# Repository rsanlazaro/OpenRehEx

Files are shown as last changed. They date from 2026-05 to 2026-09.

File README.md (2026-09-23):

# OpenRehEx
**Open-Source Lower Limb Rehabilitation Exoskeleton**

OpenRehEx is an open-source lower-limb rehabilitation exoskeleton that integrates
motor **torque, speed, and position feedback** using CubeMars AK70-10 actuators,
biomechanically inspired gait trajectories, and a CAN-based embedded control system.

This repository provides **all design files and source code** required to reproduce,
modify, and extend the system.

---

## Project Overview

**OpenRehEx** is designed to promote:

- Accessibility in rehabilitation robotics
- Reproducible research
- Rapid prototyping and customization

The project includes:

- CAD design of a bilateral lower-limb exoskeleton with 3 actuated joints per leg
  (hip, knee, ankle — 6 DoF in total, sagittal plane)
- MATLAB app for biomechanically scaled gait trajectories
- CAN protocol implementation for CubeMars AK70-10 motors (MIT mode)
- Arduino firmware for real-time control of all six motors with safety supervision
- Integrated motor feedback (position, speed, torque)
- Real-time visualization interface in Python

---

## System Architecture

The complete system is organized into five stages. The full description, control
hierarchy, operating states and loop timing are in
[`docs/system_architecture.pdf`](docs/system_architecture.pdf).

1. **Trajectory Generation** — Gait trajectories are generated in MATLAB from
   gait speed, step length, amplitude scale and smoothness. The exported CSV is
   converted into a flash lookup table for the firmware
   (`Arduino/Motor_Control/gait_trajectory.h`) with `csv_to_header.py`.

2. **Microcontroller (Control)** — An Arduino MEGA 2560 runs a fixed-rate 200 Hz
   loop that tracks the gait trajectory on all six joints (left leg shifted by
   50 % of the stride), enforces the mechanical range of motion, supervises the
   motors, and handles CAN communication.

3. **CAN Bus Interface** — An MCP2515 module (SPI) bridges the Arduino and the
   CAN bus at 1 Mbps. Only two wires (CAN_H and CAN_L) daisy-chain all motors,
   with a 120 Ω termination resistor at each end of the bus.

4. **Actuation** — Six CubeMars AK70-10 motors, powered by an external 24–48 V DC
   supply through a fuse and a hardware emergency stop, controlled in MIT
   (impedance) mode: τ = kp·(p_ref − p) + kd·(v_ref − v) + τ_ff.

5. **Visualization** — The control MEGA sends telemetry over UART to a second
   Arduino MEGA 2560, which validates it and forwards it over USB to a Python
   interface for real-time monitoring of trajectory tracking, torque and
   velocity. This stage is optional; the exoskeleton operates independently of it.

Wiring for the complete system: [`docs/wiring_diagram.pdf`](docs/wiring_diagram.pdf).
Single-motor bench wiring: [`CAN_Protocol/CAN_connection.png`](CAN_Protocol/CAN_connection.png).

---

## Degrees of Freedom

| Joint  | Plane | Actuation | Range of motion (deg) | CAN ID (Right / Left) |
|---|---|---|---|---|
| Hip | Sagittal plane | AK70-10 | −20 (extension) to 40 (flexion) | 0x01 / 0x04 |
| Knee | Sagittal plane | AK70-10 | 0 to 50 (flexion) | 0x02 / 0x05 |
| Ankle  | Sagittal plane | AK70-10 | −20 (plantarflexion) to 20 (dorsiflexion) | 0x03 / 0x06 |

The ranges are the mechanical limits used by the MATLAB generator and enforced as
soft limits by the firmware.

---

## Repository Structure

```
OpenRehEx/
├── CAD/                                  # SolidWorks parts (.SLDPRT) and assemblies (.SLDASM)
│   ├── Hip/                              # Left/right hip covers, waist supports, side supports
│   ├── Knee/                             # Left/right thigh links, knee covers, motor base
│   ├── Ankle/                            # Left/right shank links, foot plates, ankle covers
│   └── Assembly/                         # Full assembly (OpehRehEx_V1.SLDASM), back, waist, AK70-10 model
├── MATLAB/
│   ├── trajectory_generator.m            # App: gait trajectory generator and exporter
│   ├── gait_parameters.m                 # Reference table of gait parameters (slow/normal/fast)
│   └── examples/                         # Slow, normal and fast gait demos + run_all_examples.m
├── Arduino/
│   ├── main.ino                          # Control MEGA firmware (6 motors, console, telemetry)
│   ├── CAN_Driver/
│   │   └── CAN_Driver.h                  # AK70-10 MIT protocol over MCP2515 (header-only)
│   ├── Motor_Control/
│   │   ├── Motor_Control.h               # State machine, gait reference, safety supervisor
│   │   ├── gait_trajectory.h             # Auto-generated gait table (PROGMEM)
│   │   └── csv_to_header.py              # MATLAB CSV → gait_trajectory.h
│   └── Graphs_visualization/
│       ├── ArduinoMEGA_receiveSerial/    # Visualization MEGA firmware (UART → USB relay)
│       ├── GUI_plotting_V4.py            # Real-time plotting interface (PyQt5 + Matplotlib)
│       └── requirements.txt
├── CAN_Protocol/
│   ├── motor_commands.md                 # Frame layouts, scaling, IDs, command sequence
│   ├── CAN_connection.png                # Single-motor bench wiring
│   └── CubeMarstool_V1.32.exe            # Vendor tool (IDs, firmware, MIT limits)
├── docs/
│   ├── system_architecture.pdf
│   ├── wiring_diagram.pdf
│   └── src/build_docs.py                 # Regenerates both PDFs
├── Trajectory_generation.m               # Standalone function version of the generator (legacy)
├── LICENSE
└── README.md
```

---

## Hardware Requirements

| Component | Specification / Model |
|---|---|
| Actuators | CubeMars AK70-10 (24–48 V) × 6 |
| Microcontroller | Arduino MEGA 2560 × 2 (control + visualization) |
| CAN interface module | MCP2515 with 8 MHz crystal |
| CAN transceiver | TJA1050 (integrated in the MCP2515 module) |
| Power supply | DC 24–48 V, sized for the combined current of six motors |
| Safety | Main fuse + hardware emergency stop on motor V+ |
| Bus termination | 120 Ω resistors × 2 (one can be the MCP2515 J1 jumper) |
| Cables | Twisted pair for CAN, 2 × USB (A–B) to the PC |

> The 15 A supply shown in `CAN_connection.png` was used for the single-motor
> bench setup. Size the supply, fuse and wiring for all six motors.

---

## MATLAB Trajectory Generator

`trajectory_generator.m` is a MATLAB app that generates **hip, knee, and ankle
trajectories** for both legs from:

- Gait speed (m/s) and step length (m) — cadence, step time and stride time are derived
- Number of gait cycles and points per trajectory
- Amplitude scale (for progressive, sub-maximal range of motion)
- Smoothness level (1–10)

Keypoints are based on Oberg et al. (1993), Kwon et al. (2015), Lim et al. (2017) and
Judge et al. (1996), clamped to the exoskeleton's mechanical limits and interpolated
with periodic PCHIP. Presets are provided for slow, normal and fast gait.

**Exports** (written to the current folder):

| File | Content |
|---|---|
| `exoskeleton_trajectories.mat` | Trajectories (both legs), parameters, limits, references |
| `exoskeleton_trajectories.csv` | `Time_s, Hip, Knee, Ankle` (right leg) |
| `exoskeleton_trajectories.txt` | Same data with a commented header |
| `exoskeleton_trajectories_arduino.txt`| Float arrays, both legs, ×10 downsampled, ×0.75 scaled |

The firmware uses the **CSV**, converted to a compact integer table stored in flash:

```
python Arduino/Motor_Control/csv_to_header.py --csv exoskeleton_trajectories.csv --units deg --cycles 3
```

`--cycles` must match the number of gait cycles set in the app, and `--units` the
selected output unit. `python csv_to_header.py --baseline` rebuilds the default table
(nominal gait, 1.40 m/s, 0.73 m step).

The same model is available as a function in `Trajectory_generation.m`:

```matlab
[hip, knee, ankle, t] = generate_exoskeleton_trajectories('gait_speed', 1.0, 'step_length', 0.6, 'smoothness', 9);
```

Joint conventions: hip and knee positive = flexion; ankle positive = dorsiflexion.

---

## Firmware

`Arduino/main.ino` runs on the control MEGA and uses the two header-only modules
in `CAN_Driver/` and `Motor_Control/`. Dependency: **`mcp_can`** by coryjfowler
(Arduino Library Manager).

**Operating states:** DISABLED → HOLD → RAMP_IN → WALKING → RAMP_OUT → HOLD, plus
FAULT. Transitions into and out of walking are 3 s cosine ramps.

**Safety supervision:** the controller enters FAULT (damping only, kp = 0) if a motor
does not reply for 50 ms, a joint leaves its range by more than 0.15 rad, or a motor
reports an error code. FAULT is not a substitute for the hardware emergency stop.

**Operator console** (Serial Monitor on the control MEGA, 115200 baud):

| Key | Action |
|---|---|
| `e` | Enable: enter MIT mode, zero encoders, hold posture |
| `s` | Start walking (ramp in) |
| `p` | Pause: ramp back to neutral standing and hold |
| `d` | Disable: exit MIT mode (motors become free) |
| `c` | Clear a fault and hold the current posture |
| `z` | Set encoder zero at the current posture (DISABLED / HOLD only) |
| `+` `-` | Amplitude ± 0.05 (0 – 1, default 0.5) |
| `f` `l` | Stride time − / + 0.25 s (0.8 – 10 s, default 3 s) |
| `?` | Status: joint positions, torques, faults, loop timing |

Joint IDs, directions, soft limits and gains (default kp = 60 N·m/rad,
kd = 1 N·m·s/rad) are set in the `JOINTS[]` table of `main.ino`.

---

## CAN Protocol

Motor commands and feedback use the CubeMars MIT protocol (CAN 2.0A, 1 Mbps, 8-byte
frames): special frames to enter/exit MIT mode and set zero, one command frame
(position, velocity, kp, kd, feed-forward torque) and one reply (motor ID, position,
velocity, torque, and on newer firmware temperature and error code) per motor per
cycle. Full definitions, scaling ranges, worked examples and troubleshooting are in
[`CAN_Protocol/motor_commands.md`](CAN_Protocol/motor_commands.md).

---

## Visualization Interface

`GUI_plotting_V4.py` plots the six motors in real time (right leg / left leg columns)
and can switch between **position vs. reference**, **torque**, and **velocity**
(computed from position and timestamp). It includes a median-based spike filter,
left/right range-of-motion comparison per joint, a restart button, and export of the
session to `session_data` TXT/CSV files.

Telemetry format (one line per sample, integers):

```
motor_id,timestamp_ms,ref_mrad,pos_mrad,torque_mNm
```

---

## Getting Started

1. **Mechanical assembly** — Open `CAD/Assembly/OpehRehEx_V1.SLDASM`, export the parts
   to STL, then print and assemble them.
2. **Motor setup** — With CubeMarsTool, assign each motor a unique CAN ID (0x01–0x06,
   one motor at a time) and read its MIT scaling limits. Select the matching limits
   in `setup()` of `main.ino` (see `motor_commands.md`, section 5).
3. **Wiring** — Follow `docs/wiring_diagram.pdf`.
4. **Trajectory generation** — Generate trajectories in MATLAB and convert the CSV
   with `csv_to_header.py`.
5. **Firmware upload** — Install `mcp_can`, then upload `Arduino/main.ino` to the
   control MEGA and `Arduino/Graphs_visualization/ArduinoMEGA_receiveSerial/` to the
   visualization MEGA.
6. **First run** — Without a user, place the exoskeleton at neutral standing posture,
   press `e`, and verify each joint moves in the correct direction (flip `direction`
   in `JOINTS[]` if needed). Test the emergency stop.
7. **Visualization** — `pip install -r Arduino/Graphs_visualization/requirements.txt`,
   set `COM_PORT` in `GUI_plotting_V4.py` to the visualization MEGA's port, and run it.

> **Safety:** the encoders are zeroed on every enable, so always enable at neutral
> posture. Start with low amplitude and long stride times, and support the user
> (harness or parallel bars) before disabling the motors or pressing the E-stop.

---

## License

This project is released under the MIT License, unless otherwise stated.
See [LICENSE](LICENSE) for details.

---

## Citation

If you use OpenRehEx in your research, please cite:

```bibtex
@article{OpenRehEx2026,
  title   = {OpenRehEx: A Lower Limb Open-Source Rehabilitation Exoskeleton
             with Integrated Motor Torque, Speed, and Position Feedback},
  author  = {Rafael P\'{e}rez-San L\'{a}zaro, Fuentes-Aguilar Rita Q., Isaac Chairez},
  year    = {2026}
}
```

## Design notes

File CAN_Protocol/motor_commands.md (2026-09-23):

# CubeMars AK70-10 — CAN Motor Commands (MIT mode)

This document describes every CAN frame that OpenRehEx exchanges with the six
CubeMars **AK70-10** actuators, and how those frames are produced and decoded by
`Arduino/CAN_Driver/CAN_Driver.h`.

> **Source of truth.** Frame layouts follow the CubeMars *AK Series Actuator
> Manual*, section "MIT power mode communication protocol". Scaling ranges can
> change between firmware versions — always confirm them for **your** motors
> with `CubeMarstool_V1.32.exe` (in this folder) before running the exoskeleton
> with a person in it.

---

## 1. Bus configuration

| Parameter | Value |
|---|---|
| Standard | CAN 2.0A (11-bit standard identifier) |
| Bit rate | 1 Mbps (AK factory default) |
| Payload | 8 bytes (commands), 6 or 8 bytes (replies) |
| Topology | Linear bus, daisy-chained through each motor's CAN IN/OUT port |
| Termination | 120 Ω between CAN_H and CAN_L at **both** physical ends |
| Controller | MCP2515 + TJA1050 module, 8 MHz crystal, SPI to Arduino MEGA 2560 |
| Arduino library  | `mcp_can` by coryjfowler |

### Motor ID map

IDs are assigned with CubeMarsTool (factory default is `0x01` for every motor,
so each motor must be re-addressed **one at a time** before joining the bus).
The map matches `JOINTS[]` in `Arduino/main.ino` and `MOTOR_META` in
`Arduino/Graphs_visualization/GUI_plotting_V4.py`.

| CAN ID | Joint | Side  |
|:---:|---|---|
| `0x01` | Hip | Right |
| `0x02` | Knee | Right |
| `0x03` | Ankle | Right |
| `0x04` | Hip | Left  |
| `0x05` | Knee | Left  |
| `0x06` | Ankle | Left  |

---

## 2. Special commands

Sent to the motor's CAN ID, 8 data bytes. Only the last byte changes.

| Command | Data (hex) | Effect | Driver call |
|---|---|---|---|
| Enter MIT mode | `FF FF FF FF FF FF FF FC` | Enables the motor; it starts answering MIT frames | `enterMit(id)` |
| Exit MIT mode | `FF FF FF FF FF FF FF FD` | Disables the motor (free / back-drivable) | `exitMit(id)` |
| Set zero position  | `FF FF FF FF FF FF FF FE` | Current output-shaft angle becomes 0 rad | `setZero(id)` |

> ⚠ **Set zero** redefines the joint reference. OpenRehEx sends it on every
> `enable` (`zero_on_enable = true`, same behaviour as the original sketch), so
> the exoskeleton **must be in the neutral standing posture** (hip 0°, knee 0°,
> ankle 0°) when the operator types `e`. Set `zero_on_enable = false` in
> `DEFAULT_SETTINGS` once zeroing is done with a fixture instead.

---

## 3. Control command (Arduino → motor)

Every control cycle the firmware sends one 8-byte frame per motor. The motor
closes an impedance loop at the output shaft:

```
tau = kp * (p_des - p) + kd * (v_des - v) + t_ff
```

### Fields

| Field | Bits | Unit | Meaning |
|---|:----:|---|---|
| `p_des` | 16 | rad | Desired output position |
| `v_des` | 12 | rad/s | Desired output velocity |
| `kp` | 12 | N·m/rad | Position (stiffness) gain |
| `kd` | 12 | N·m·s/rad | Velocity (damping) gain |
| `t_ff`  | 12 | N·m | Feed-forward torque |

### Byte layout

| Byte | Bits 7‥4 | Bits 3‥0 |
|:----:|---|---|
| 0 | `p_des[15:8]` | |
| 1 | `p_des[7:0]` | |
| 2 | `v_des[11:4]` | |
| 3 | `v_des[3:0]` | `kp[11:8]` |
| 4 | `kp[7:0]` | |
| 5 | `kd[11:4]` | |
| 6 | `kd[3:0]` | `t_ff[11:8]` |
| 7 | `t_ff[7:0]` | |

---

## 4. Reply (motor → Arduino)

The motor answers **each** control frame (and only then). The reply is sent to
the master ID (default `0x00`); the motor ID is inside the payload, so replies
are routed by **byte 0**, not by the CAN identifier.

| Byte | Content |
|:----:|---|
| 0 | Motor ID |
| 1 | `p[15:8]` |
| 2 | `p[7:0]` |
| 3 | `v[11:4]` |
| 4 | `v[3:0]` (high nibble) · `i[11:8]` (low nibble) |
| 5 | `i[7:0]` |
| 6 | Driver temperature *(firmware ≥ V2 only)* |
| 7 | Error code *(firmware ≥ V2 only)* |

`i` is scaled with the torque range (`T_MIN … T_MAX`), so it decodes directly
to output torque in N·m.

### Error codes (byte 7)

| Code | Meaning |
|:----:|---|
| 0 | No fault |
| 1 | Motor over-temperature |
| 2 | Over-current |
| 3 | Over-voltage |
| 4 | Under-voltage |
| 5 | Encoder fault |
| 6 | Phase-current unbalance  |

With `fault_on_motor_error = true` any non-zero code puts the controller in
`FAULT` (damping only). Replies of 6 bytes (older firmware) carry no status and
never trigger this check. The temperature byte is stored raw (`temp_raw`)
because its offset differs between firmware versions.

---

## 5. Scaling (float ↔ integer)

All values are linearly mapped onto unsigned integers:

```
x_int   = round( (x - x_min) * (2^bits - 1) / (x_max - x_min) )
x_float =  x_int * (x_max - x_min) / (2^bits - 1) + x_min
```

Values outside `[x_min, x_max]` are saturated before packing.

### Ranges

| Symbol | AK70-10 (CubeMars manual) — **used by default** | Original sketch (`AK_LEGACY_SKETCH_LIMITS`) |
|---|:---:|:---:|
| `P_MIN / P_MAX` | −12.5 / 12.5 rad | −12.5 / 12.5 rad |
| `V_MIN / V_MAX` | −50 / 50 rad/s | −30 / 30 rad/s |
| `KP_MIN / KP_MAX` | 0 / 500 N·m/rad | 0 / 500 N·m/rad |
| `KD_MIN / KD_MAX` | 0 / 5 N·m·s/rad | 0 / 5 N·m·s/rad |
| `T_MIN / T_MAX` | −25 / 25 N·m | −18 / 18 N·m |

> ⚠ **Why this matters.** If the firmware uses ±50 rad/s and ±25 N·m but the
> code packs with ±30 and ±18, every velocity and torque value is wrong by a
> constant factor (e.g. torque read as 72 % of its real value), while position
> still looks correct. Some third-party drivers list ±24 N·m for AK70-10
> firmware V1.1. Read the ranges in CubeMarsTool and select the matching
> constant in `setup()` (`canBus.setLimits(...)`).

### Resolution (with the default ranges)

| Quantity | Step |
|---|---|
| Position | 0.00038 rad (0.022°) |
| Velocity | 0.0244 rad/s  |
| Torque | 0.0122 N·m |
| `kp` | 0.122 N·m/rad |
| `kd` | 0.0012 N·m·s/rad |

### Worked examples (default ranges)

| `p_des` | `v_des` | `kp` | `kd` | `t_ff` | Frame (hex) |
|---:|---:|-----:|-----:|---:|---|
| 0 | 0 | 0 | 0 | 0 | `80 00 80 00 00 00 08 00` — passive, used to read state |
| 0.5 | 0 | 60 | 1 | 0 | `85 1E 80 01 EB 33 38 00` |
| 1.234 | −3.2 | 60 | 1 | 2.5 | `8C A2 77 C1 EB 33 38 CC` |

---

## 6. Command sequence used by the firmware

```
enable (console 'e')
  for id in 1..6:  ENTER_MIT(id) ; [SET_ZERO(id)]
  for id in 1..6:  PASSIVE(id) -> wait reply (≤ 5 attempts) -> store position
  state = HOLD (reference = measured posture)

every control period (default 200 Hz)
  for id in 1..6:
      send MIT command(id)            # p_des, v_des (feed-forward), kp, kd, t_ff = 0
      wait reply from id (≤ 1.5 ms)   # one request/one reply keeps the MCP2515
                                      # 2-frame RX buffer from overflowing
  supervise:  no reply > 50 ms | angle outside limits + 8.6° | error code ≠ 0
              -> FAULT: kp = 0, kd = 2, t_ff = 0 on all joints

disable (console 'd')
  for id in 1..6:  EXIT_MIT(id)       # motors become free: support the limb!
```

**Why request/reply per motor?** The MCP2515 has only two receive buffers. If
six commands are sent back-to-back, up to six replies arrive within ~0.7 ms and
four are lost. Waiting for each reply before sending the next command costs
~0.4–0.6 ms per motor, which still fits inside a 5 ms (200 Hz) cycle. The
console command `?` prints the worst-case loop time and the overrun counter; if
overruns increase, set `CONTROL_HZ` to 100.

---

## 7. Telemetry to the PC (not CAN)

The control MEGA sends one line per control cycle on `Serial1` (round-robin over
the six motors). The visualization MEGA validates and forwards it over USB to
`GUI_plotting_V4.py`.

```
motor_id,timestamp_ms,ref_mrad,pos_mrad,torque_mNm\n
e.g.  2,445473,611,598,4130
```

All values are integers in **joint coordinates** (sign convention of
`trajectory_generator.m`: hip/knee + flexion, ankle + dorsiflexion).

---

## 8. Servo mode (not used)

AK actuators also support a *servo mode* that uses **extended 29-bit IDs**
(`control_mode << 8 | motor_id`) and different payloads (duty, current, RPM,
position). OpenRehEx uses MIT mode only because it exposes the impedance gains
needed for assist-as-needed control. Do not mix both modes on the same bus.

---

## 9. Troubleshooting

| Symptom | Likely cause / fix |
|---|---|
| `MCP2515 init failed` | SPI wiring, CS ≠ D53, or crystal is 16 MHz → use `MCP_16MHZ` |
| No replies, `FAULT_ENABLE_FAILED` | Wrong ID, motor not powered, missing termination, CAN_H/CAN_L swapped |
| Only one motor answers | All motors still have ID `0x01` — re-address them one by one |
| Position OK, torque/velocity look scaled  | `MitLimits` do not match the firmware (section 5) |
| Joint moves the wrong way | Flip `direction` for that joint in `JOINTS[]` |
| Random `FAULT_NO_REPLY` while walking | Bus length/stubs too long, missing common ground, loop overruns |
| Motor jumps on enable | Exoskeleton was not at neutral posture when zero was set |

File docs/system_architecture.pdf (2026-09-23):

# OpenRehEx — System Architecture

Open-source 6-DoF lower-limb rehabilitation exoskeleton · end-to-end data flow from trajectory design to actuation and monitoring

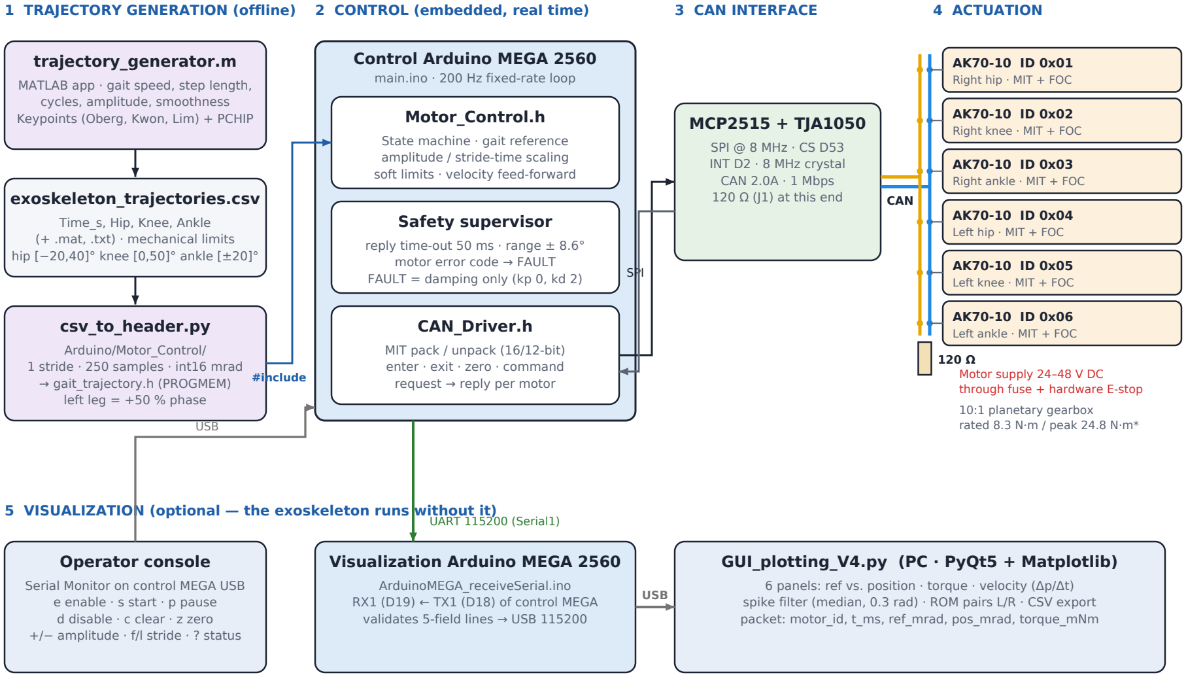
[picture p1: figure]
1 TRAJECTORY GENERATION (offline); trajectory_generator.m; MATLAB app · gait speed, step length, cycles, amplitude, smoothness Keypoints (Oberg, Kwon, Lim) + PCHIP; exoskeleton_trajectories.csv; Time_s, Hip, Knee, Ankle (+ .mat, .txt) · mechanical limits hip [−20,40]° knee [0,50]° ankle [±20]°; csv_to_header.py; Arduino/Motor_Control/ 1 stride · 250 samples · int16 mrad → gait_trajectory.h (PROGMEM) left leg = +50 % phase; 2 CONTROL (embedded, real time); Control Arduino MEGA 2560; main.ino · 200 Hz fixed-rate loop; Motor_Control.h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

OpenRehEx · System architecture · github.com/rsanlazaro/OpenRehEx | Page 1 of 3
5 VISUALIZATION (optional — the exoskeleton runs | without it)

### GUI_plotting_V4.py (PC · PyQt5 + Matplotlib)

6 panels: ref vs. position · torque · velocity (Δp/Δt)
spike filter (median, 0.3 rad) · ROM pairs L/R · CSV export packet: motor_id, t_ms, ref_mrad, pos_mrad, torque_mNm

* Vendor-listed AK70-10 figures; confirm against the datasheet of your units. Colors: yellow CAN_H · blue CAN_L · green UART · gray USB.

# Control Architecture & Firmware

### Control hierarchy, operating states and the real-time cycle of the control MEGA

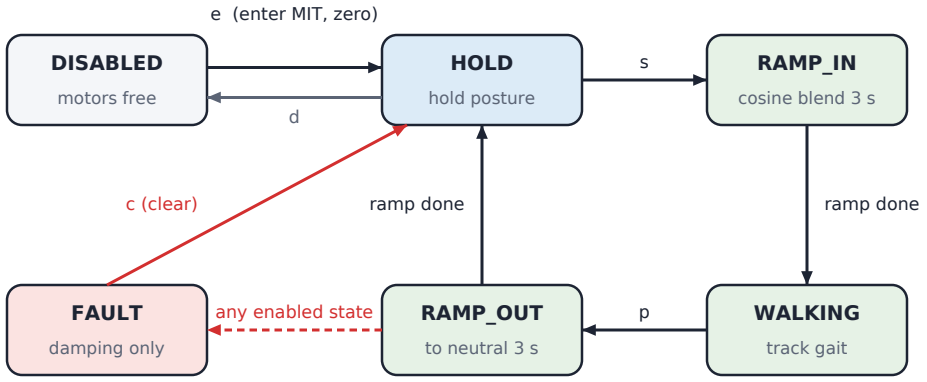
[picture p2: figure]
DISABLED; motors free; HOLD; hold posture; RAMP_IN; cosine blend 3 s; WALKING; track gait; RAMP_OUT; to neutral 3 s; FAULT; damping only; e (enter MIT, zero); ramp done; c (clear); any enabled state

OpenRehEx · System architecture · github.com/rsanlazaro/OpenRehEx | Page 2 of 3

## Control hierarchy

HIGH LEVEL — adaptation (roadmap)

Q-learning agents: Recovery Estimator + Therapy Tuner
Adjust amplitude, stride time and impedance between sessions/strides

MID LEVEL — interaction (roadmap)

Admittance control on measured joint torque
Converts user effort into reference deviations (assist-as-needed)

LOW LEVEL — implemented in this repo

Trajectory tracking + MIT impedance on each AK70-10
τ = kp (p_ref − p) + kd (v_ref − v) + τ_ff · 200 Hz on the MEGA

Dashed = planned research layers (not in the firmware yet). Their outputs map onto exo.setAmplitude(), exo.setStrideTime(), JointConfig kp/kd and the τ_ff slot in buildCommand().

## Operating states (Motor_Control.h)

FAULT triggers: no reply from a motor for > 50 ms · measured angle outside the soft limits by more than 0.15 rad · non-zero motor error code (firmware ≥ V2). In FAULT the motors stay in MIT mode with kp = 0, kd = 2 N·m·s/rad: the limbs are slowed, not held. Only the hardware E-stop removes motor power.

## Real-time cycle (CONTROL_HZ = 200 → 5 ms)

ref

M1 | M2 | M3 | M4 | M5 | M6

sup

tlm | slack · console parsing
0 ms | 1 ms | 2 ms | 3 ms | 4 ms | 5 ms

ref = compute references (gait table interpolation, amplitude slew, ramps, soft limits) · M1…M6 = send MIT frame to motor i, then wait ≤ 1.5 ms for its reply
sup = safety supervisor · tlm = one telemetry line on Serial1.
Per-motor request/reply is required because the MCP2515 has only two RX buffers. Durations shown are estimates for a 16 MHz MEGA; check them with the '?' command (max exec µs, overruns). CAN load ≈ 12 frames × ~0.13 ms = 1.6 ms per cycle (≈ 30 % of the bus at 200 Hz). Telemetry: 200 lines/s × ~25 B ≈ 5 kB/s (≈ 45 % of 115200 baud) → each motor is plotted at ≈ 33 Hz.

## Reference generation

phase φ ← φ + Δt / T_stride (mod 1) | q_ref,R(j) = A · g_j(φ) | q_ref,L(j) = A · g_j(φ + 0.5)
g_j = PROGMEM table of joint j (hip, knee, ankle), 250 samples, linear interpolation. A ∈ [0, 1] slews at 0.1 /s; T_stride ∈ [0.8, 10] s (default 3 s, A = 0.5).
motor = direction · joint + offset | v_ref = Δq_ref / Δt (clamped ±6 rad/s) | τ_ff = 0 (slot for gravity / interaction compensation)

# Repository Map & Interfaces

### Where each part of the system lives and the data contracts between them

OpenRehEx · System architecture · github.com/rsanlazaro/OpenRehEx | Page 3 of 3

## Repository layout

Path | | Content
CAD/Hip, Knee, Ankle, Assembly | | SolidWorks parts/assemblies (OpehRehEx_V1.SLDASM, AK70-10.SLDPRT)
MATLAB/trajectory_generator.m | | App: biomechanical gait trajectories → .csv / .mat / .txt
MATLAB/gait_parameters.m, examples/ | | Reference gait tables · slow / normal / fast demos
Arduino/main.ino | | Control MEGA firmware: joint table, 200 Hz loop, console, telemetry
Arduino/CAN_Driver/CAN_Driver.h | | AK70-10 MIT protocol over MCP2515 (header-only)
Arduino/Motor_Control/Motor_Control.h | | State machine, gait reference, safety supervisor (header-only)
Arduino/Motor_Control/gait_trajectory.h | Auto-generated PROGMEM gait table (1 stride, mrad)
Arduino/Motor_Control/csv_to_header.py | | MATLAB CSV → gait_trajectory.h converter
Arduino/Graphs_visualization/ | | Relay MEGA sketch + GUI_plotting_V4.py + requirements.txt
CAN_Protocol/motor_commands.md | | Frame layouts, scaling, IDs, sequences, troubleshooting
CAN_Protocol/CubeMarstool_V1.32.exe | | Vendor tool: IDs, firmware, MIT limits, calibration
docs/ | | system_architecture.pdf, wiring_diagram.pdf, src/build_docs.py

## Data interfaces

Link | Physical | Content | Rate
MATLAB → converter | CSV | Time_s, Hip, Knee, Ankle (deg or rad, N strides) | offline
Converter → firmware | C header | int16 mrad ×3 × 250, GAIT_STRIDE_TIME_S | compile time
Control MEGA ↔ MCP2515 | SPI | mcp_can, CS D53, INT D2 | ≤ 8 MHz
MCP2515 ↔ AK70-10 ×6 | CAN 2.0A | MIT command 8 B / reply 6–8 B, IDs 0x01–0x06 | 1 Mbps
Control → Visualization MEGA | UART | id,t_ms,ref_mrad,pos_mrad,tor_mNm\n | 115200 baud
Visualization MEGA → PC | USB CDC | same 5-field lines, validated | 115200 baud
PC → Control MEGA | USB CDC | single-char console commands | 115200 baud

## Conventions

Joint angles (MATLAB, firmware, GUI): hip + flexion / − extension · knee + flexion · ankle + dorsiflexion / − plantarflexion.
Mechanical range (deg): hip [−20, 40] · knee [0, 50] · ankle [−20, 20]; used as firmware soft limits.
Motor IDs 1–3 right leg (hip, knee, ankle), 4–6 left leg; same order in main.ino JOINTS[] and GUI MOTOR_META.
Units on the wire: rad, rad/s, N·m (CAN, float-scaled); mrad and mN·m integers (UART telemetry).

Before powering with a person in the exoskeleton

1) Confirm MIT scaling limits in CubeMarsTool and select them in setup(). 2) Verify each joint's 'direction' unloaded. 3) Enable only at neutral posture (zero_on_enable).
4) Test the hardware E-stop and FAULT behaviour at low amplitude. 5) Start with A ≤ 0.5, stride ≥ 3 s and reduced kp. 6) Follow your institution's ethics / clinical-device protocol.

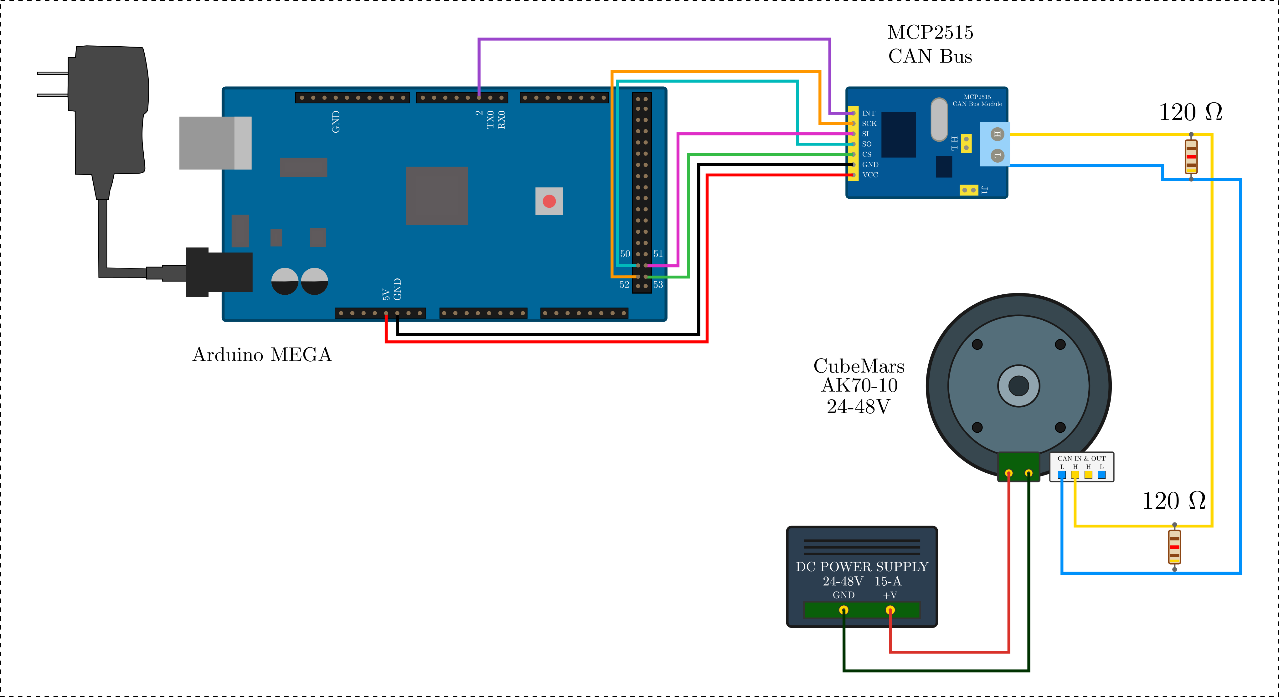
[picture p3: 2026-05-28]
CAN_Protocol/CAN_connection.png

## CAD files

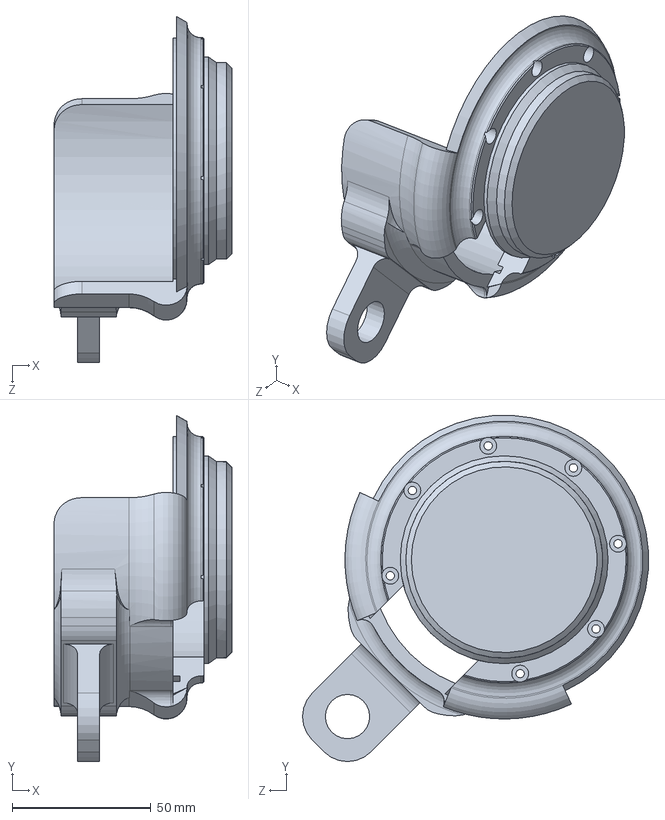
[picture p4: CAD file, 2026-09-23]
CAD/Knee/Right_cover_ankle.SLDPRT
64.2 x 124.9 x 124.9 mm

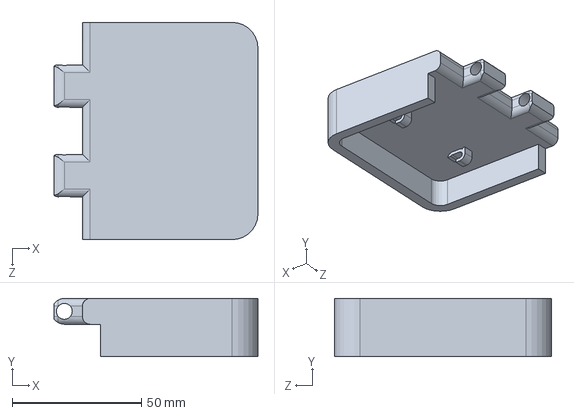
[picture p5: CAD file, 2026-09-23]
CAD/Ankle/Right_foot_up_posterior.SLDPRT
79.0 x 22.5 x 84.2 mm

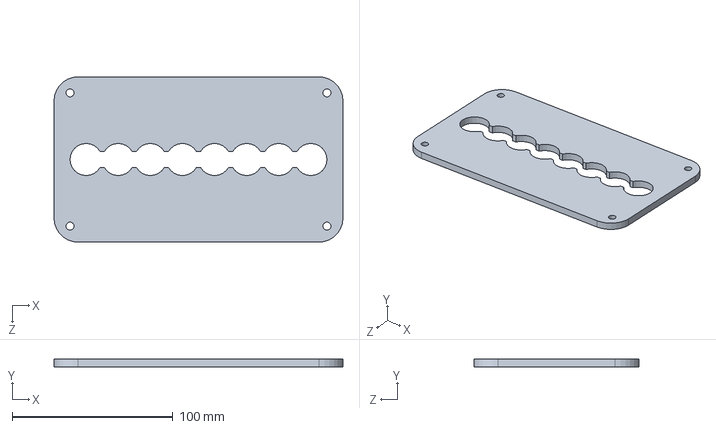
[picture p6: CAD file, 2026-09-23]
CAD/Assembly/Waist_support_joint.SLDPRT
180.0 x 4.90 x 103.0 mm

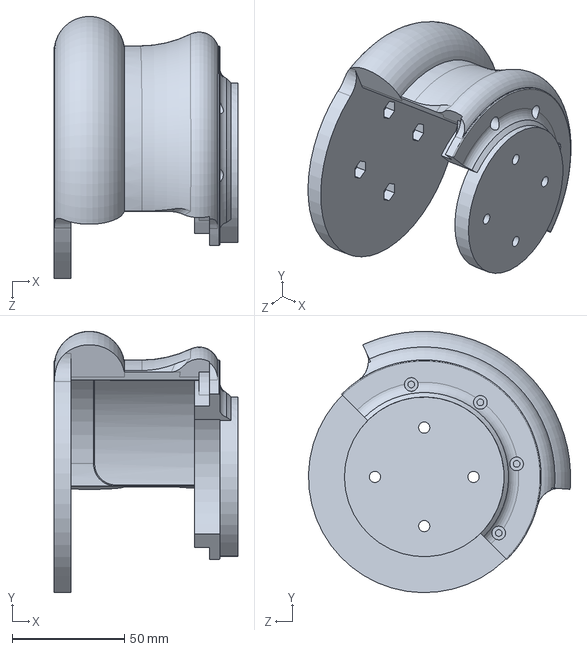
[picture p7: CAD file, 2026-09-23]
CAD/Hip/Right_cover_hip.SLDPRT
81.8 x 116.2 x 116.5 mm

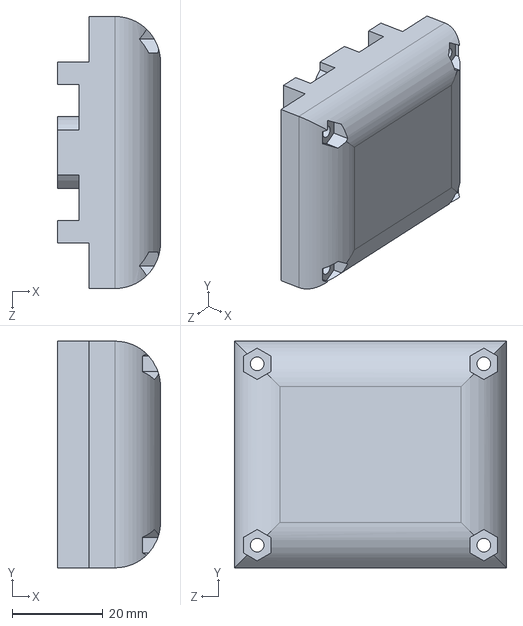
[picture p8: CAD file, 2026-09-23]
CAD/Knee/Base_1.SLDPRT
22.7 x 50.0 x 60.0 mm

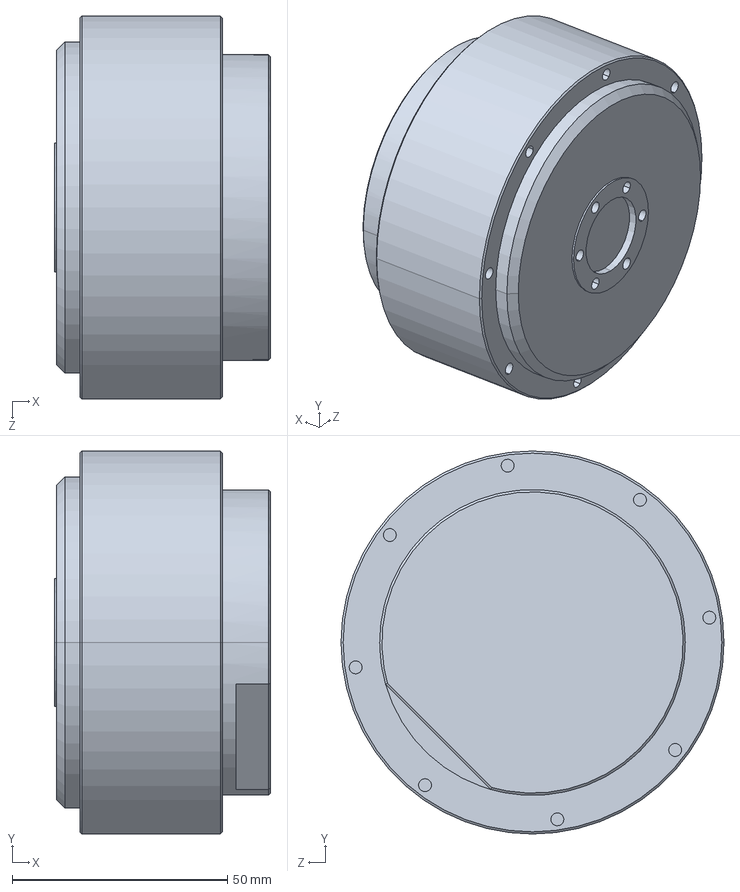
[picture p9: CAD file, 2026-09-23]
CAD/Assembly/AK70-10.SLDPRT
50.2 x 89.0 x 89.0 mm

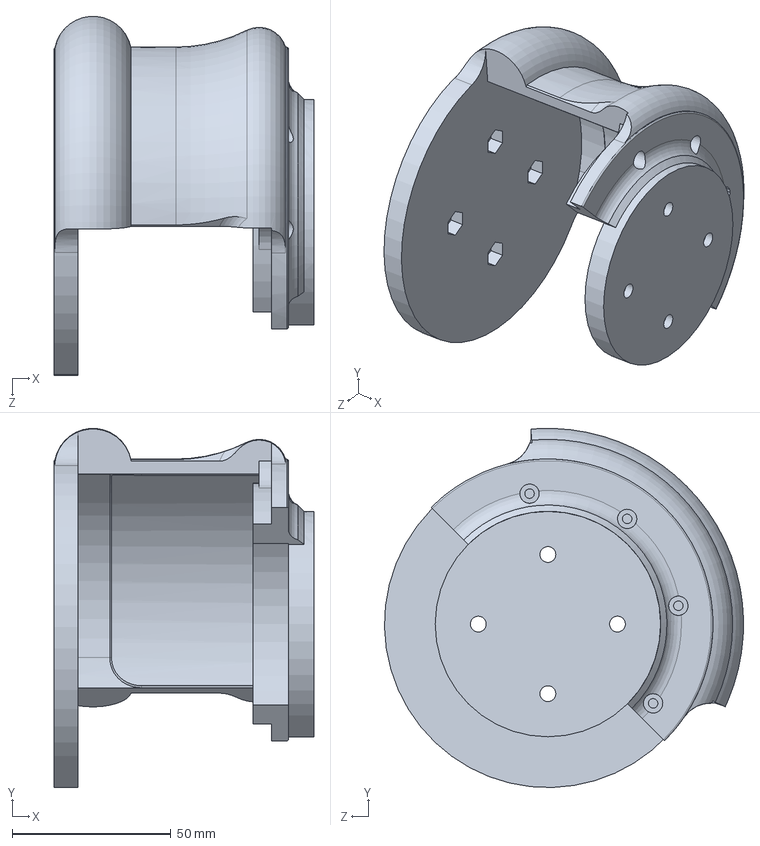
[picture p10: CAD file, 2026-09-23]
CAD/Hip/Left_cover_hip.SLDPRT
81.8 x 113.1 x 113.1 mm

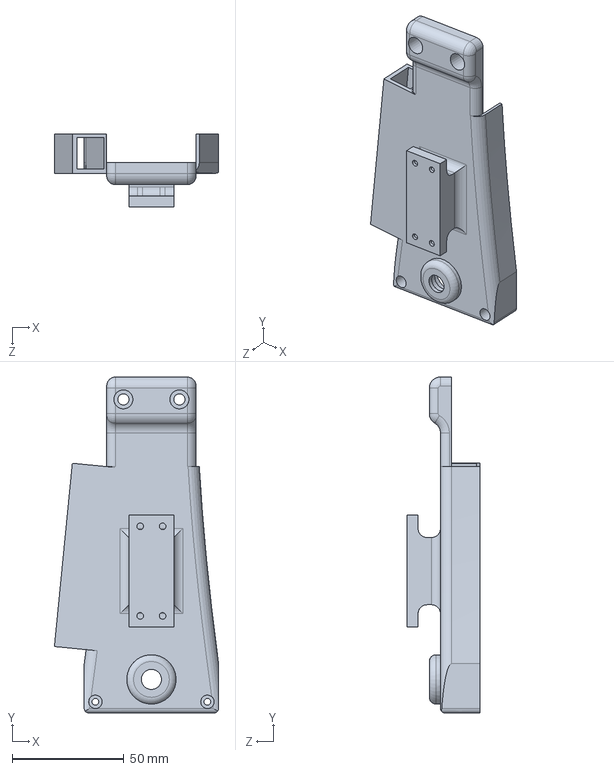
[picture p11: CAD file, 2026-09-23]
CAD/Knee/Right_front_high.SLDPRT
73.3 x 150.0 x 32.7 mm

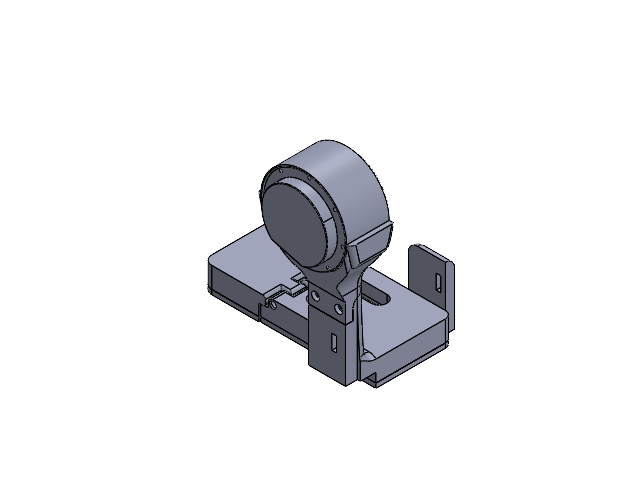
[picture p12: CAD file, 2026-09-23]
CAD/Ankle/Left_toe_V1.SLDASM
Motor_base
AK70-10
Left_foot_back_anterior
Left_foot_back_posterior
Left_foot_up_anterior
Left_foot_up_posterior

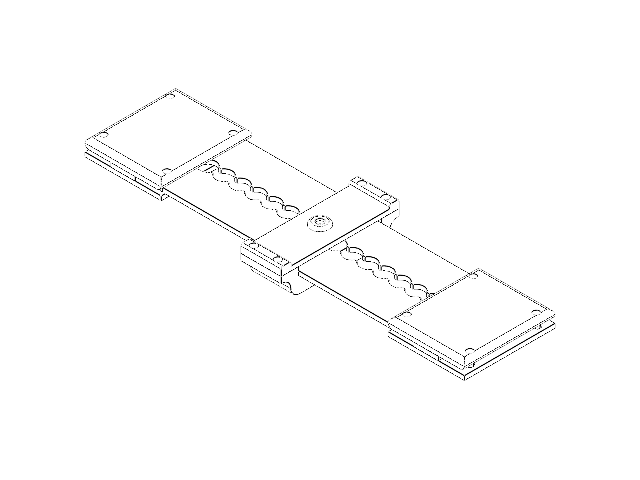
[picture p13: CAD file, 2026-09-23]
CAD/Assembly/Back_V1.SLDASM
Back_joint_2
Back_joint
Waist_support_joint x 2
Waist_support_union x 2

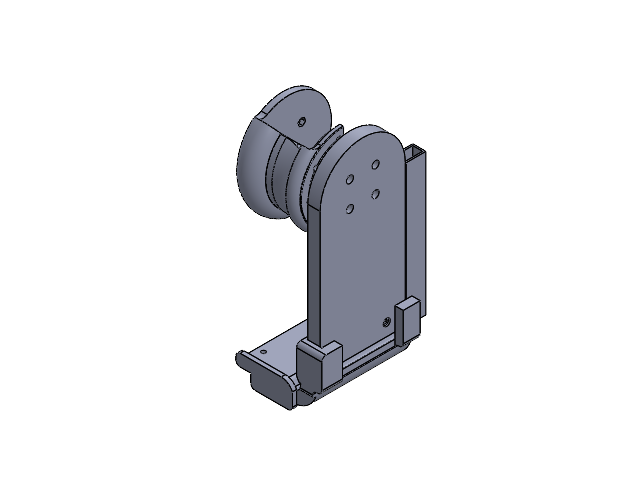
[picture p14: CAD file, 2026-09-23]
CAD/Hip/Right_hip_V1.SLDASM
Right_waist_support
Right_support_side
Right_cover_hip

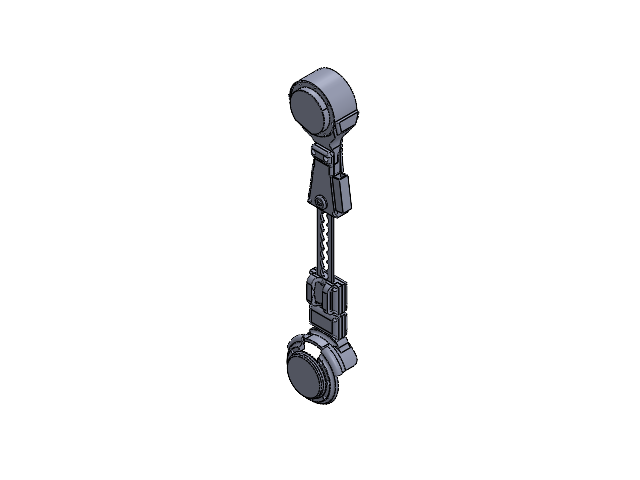
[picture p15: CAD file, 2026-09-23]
CAD/Ankle/Left_knee_ankle_V1.SLDASM
Motor_base
AK70-10
Left_back_low
Left_front_low
Link_1
Base_1
Base_2
Cover_1
Cover_2
Link_2
Left_cover_ankle

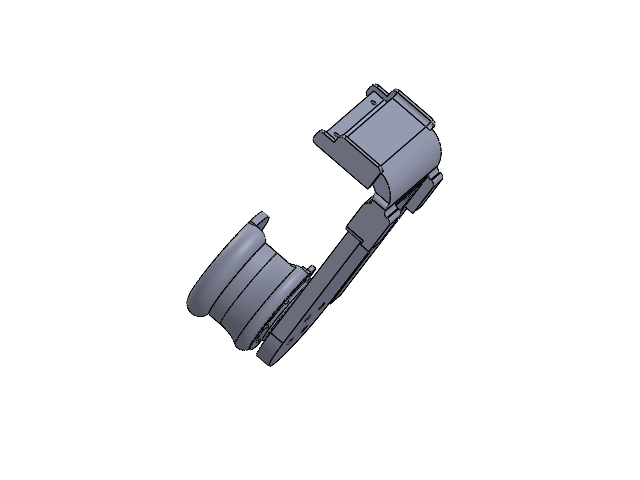
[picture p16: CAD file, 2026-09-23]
CAD/Hip/Left_hip_V1.SLDASM
Left_waist_support
Left_support_side
Left_cover_hip

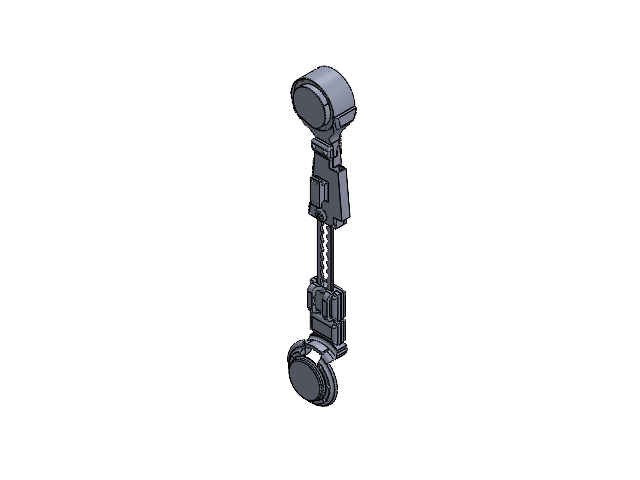
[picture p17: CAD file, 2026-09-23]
CAD/Knee/Left_hip_knee_V1.SLDASM
Motor_base
AK70-10
Left_back_high
Left_front_high
Link_1
Base_1
Base_2
Cover_1
Cover_2
Link_2
Left_cover_knee

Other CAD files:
CAD/Assembly/OpehRehEx_V1.SLDASM
CAD/Ankle/Right_knee_ankle_V1.SLDASM
CAD/Knee/Right_hip_knee_V1.SLDASM
CAD/Ankle/Right_toe_V1.SLDASM
CAD/Ankle/Left_back_low.SLDPRT
CAD/Ankle/Left_cover_ankle.SLDPRT
CAD/Ankle/Left_foot_back_anterior.SLDPRT
CAD/Ankle/Left_foot_back_posterior.SLDPRT
CAD/Ankle/Left_foot_up_anterior.SLDPRT
CAD/Ankle/Left_foot_up_posterior.SLDPRT
CAD/Ankle/Left_front_low.SLDPRT
CAD/Ankle/Right_back_low.SLDPRT
CAD/Ankle/Right_foot_back_anterior.SLDPRT
CAD/Ankle/Right_foot_back_posterior.SLDPRT
CAD/Ankle/Right_foot_up_anterior.SLDPRT
CAD/Ankle/Right_front_low.SLDPRT
CAD/Assembly/Back_joint.SLDPRT
CAD/Assembly/Back_joint_2.SLDPRT
CAD/Assembly/Link_1.SLDPRT
CAD/Assembly/Link_2.SLDPRT
CAD/Assembly/Waist_support_union.SLDPRT
CAD/Hip/Left_support_side.SLDPRT
CAD/Hip/Left_waist_support.SLDPRT
CAD/Hip/Right_support_side.SLDPRT
CAD/Hip/Right_waist_support.SLDPRT
CAD/Knee/Base_2.SLDPRT
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

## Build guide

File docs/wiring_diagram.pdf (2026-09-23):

# OpenRehEx — Wiring Diagram

Power, CAN bus, SPI and serial connections for 2 × Arduino MEGA 2560, MCP2515 and 6 × CubeMars AK70-10

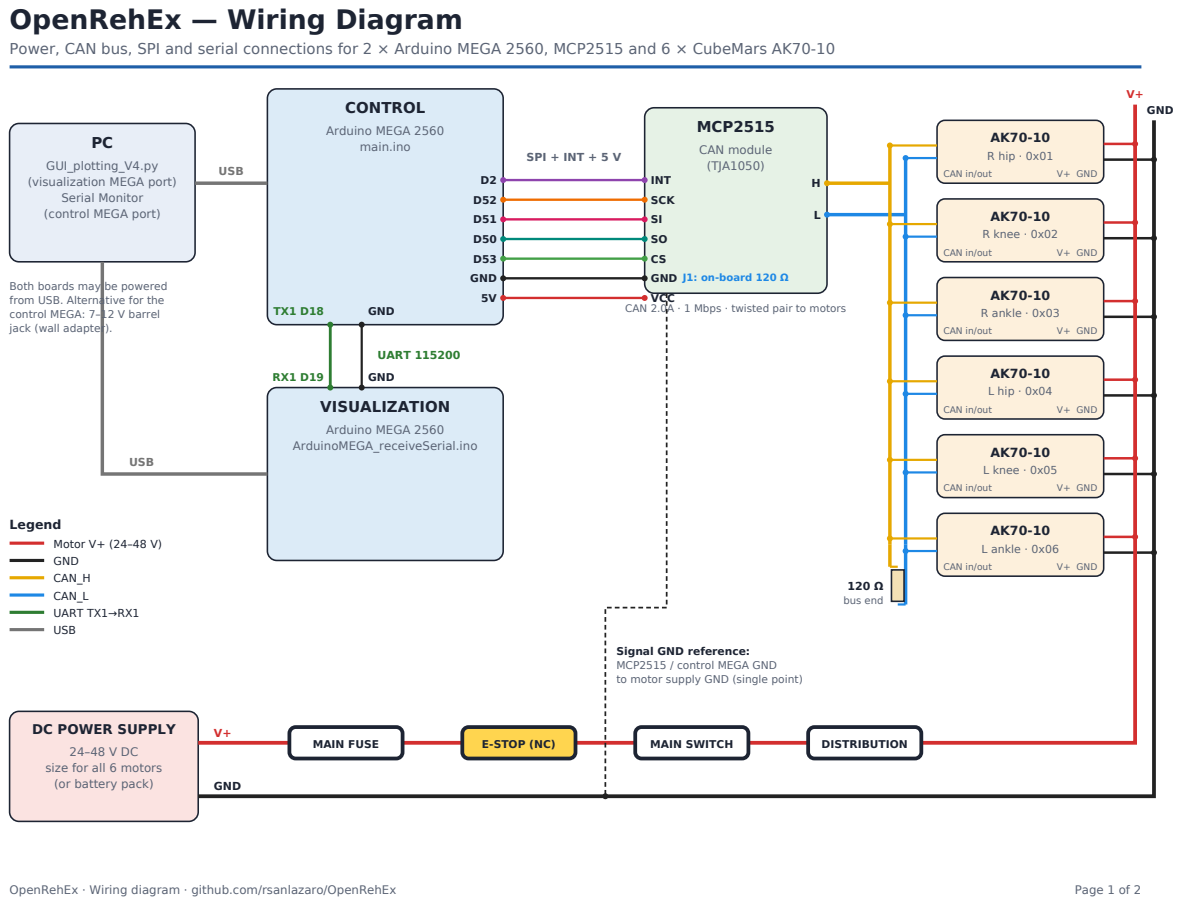
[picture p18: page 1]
OpenRehEx · Wiring diagram · github.com/rsanlazaro/OpenRehEx; Page 1 of 2; CONTROL; Arduino MEGA 2560 main.ino; MCP2515; CAN module (TJA1050); INT; SCK; GND; VCC; SPI + INT + 5 V; J1: on-board 120 Ω; VISUALIZATION; Arduino MEGA 2560 ArduinoMEGA_receiveSerial.ino; UART 115200; USB; R hip · 0x01; CAN in/out; V+ GND; R knee · 0x02; R ankle · 0x03; L hip · 0x04; L knee · 0x05; L ankle · 0x06; 120 Ω bus end; MAIN FUSE; E-STOP (NC); MAIN SWITCH; DISTRIBUTION; Legend; Motor V+ (24–48 V); CAN_H; CAN_L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

GUI_plotting_V4.py
(visualization MEGA port)
Serial Monitor
(control MEGA port)

Both boards may be powered
from USB. Alternative for the
control MEGA: 7–12 V barrel
jack (wall adapter).

CAN 2.0A · 1 Mbps · twisted pair to motors

Signal GND reference:
MCP2515 / control MEGA GND
to motor supply GND (single point)

DC POWER SUPPLY

size for all 6 motors
(or battery pack)

# Connection Tables & Checklist

### Pin-to-pin connections, bus rules and power-safety notes

OpenRehEx · Wiring diagram · github.com/rsanlazaro/OpenRehEx | Page 2 of 2

## Control MEGA ↔ MCP2515 (SPI)

MCP2515 | MEGA | Function
INT | D2 | Interrupt (optional, CAN_INT_PIN = −1 if unused)
SCK | D52 | SPI clock
SI | D51 | MOSI
SO | D50 | MISO
CS | D53 | Chip select (CAN_CS_PIN)
GND | GND | Common ground
VCC | 5V | Module supply (TJA1050 needs 5 V)

## Control MEGA ↔ Visualization MEGA (UART)

Control | Visualization | Function
TX1 | D18 | RX1 | D19 | Telemetry 115200 baud
GND | | GND | | Mandatory common ground
RX1 | D19 | (not connected) | Link is one-way

## USB

Board | Host | Use
Control MEGA | PC | Console + firmware upload
Visualization MEGA | PC | GUI data (set COM_PORT in the .py)

## CAN bus

From | To | Note
MCP2515 H | CAN_H of motor 0x01 ... 0x06 | daisy chain
MCP2515 L | CAN_L of motor 0x01 ... 0x06 | daisy chain
120 Ω | MCP2515 end (J1 jumper) | termination 1
120 Ω | after the last motor (0x06) | termination 2
Check | ≈ 60 Ω between H and L | power OFF

Use twisted pair for CAN_H/CAN_L, keep stubs short and run the bus as
a line (no star). Each motor needs a unique ID set with CubeMarsTool
before it joins the bus (all ship as 0x01). The original single-motor
drawing (CAN_Protocol/CAN_connection.png) shows the same pinout.

## Motor power

Net | Path
PSU V+ | fuse → E-stop → switch → distribution → V+ ×6
PSU GND | distribution → GND ×6 (+ signal GND reference)
Wire gauge | size for the summed current of all motors
Connectors | use the motor's power connector; check polarity

Safety & power notes

- The E-stop must physically interrupt motor V+ and be reachable by the therapist. Firmware FAULT (damping) is not a safety function.
- Disabling or cutting power makes the joints back-drivable: the user must be supported (harness / parallel bars) before 'd' or E-stop.
- Back-driven motors regenerate energy. A lab PSU cannot absorb it and the bus voltage may rise (AK error 3 = over-voltage):
prefer a battery, or add a braking resistor / TVS on the V+ bus, and keep the PSU voltage below the motor maximum.
- The 15 A supply in the README comes from the single-motor bench setup; re-size the PSU, fuse and wiring for six motors.
- Tie the MCP2515/Arduino GND to the motor supply GND at one point so CAN has a common reference; avoid ground loops through the PC.
- Verify pinouts against the datasheet/label of your AK70-10 revision before first power-up.

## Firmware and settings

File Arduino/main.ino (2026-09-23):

/*
 * =============================================================================
 *  OpenRehEx - main.ino  (formerly CubemarsAK_all_motors.ino)
 *  Control firmware for the CONTROL Arduino MEGA 2560
 * =============================================================================
 *
 *  Hardware
 *    Arduino MEGA 2560  <-SPI->  MCP2515 (8 MHz)  <-CAN 1 Mbps->  6 x AK70-10
 *    Serial  (USB, 115200) : operator console (single-character commands)
 *    Serial1 (TX1 = D18)   : telemetry to the VISUALIZATION MEGA (RX1 = D19)
 *
 *  Pins (MCP2515 module)
 *    SCK -> D52, SI -> D51, SO -> D50, CS -> D53, INT -> D2, VCC -> 5V, GND
 *
 *  Libraries
 *    mcp_can by coryjfowler (Library Manager: "mcp_can")
 *
 *  Operator console (Serial Monitor, 115200, "No line ending" or "Newline")
 *    e  enable  : enter MIT mode, zero (if enabled) and hold posture
 *    s  start   : ramp to the gait start pose and walk
 *    p  pause   : ramp back to neutral standing and hold
 *    d  disable : leave MIT mode (motors go limp - support the user first!)
 *    c  clear   : clear a FAULT and hold the current posture
 *    z  zero    : set encoder zero at current posture (DISABLED/HOLD only)
 *    + / -      : amplitude +/- 0.05       f / l : stride time -/+ 0.25 s
 *    ?          : status
 *
 *  !!! A hardware emergency stop that cuts motor power is mandatory. The
 *      firmware supervision below is NOT a substitute (see docs/wiring_diagram).
 *
 *  License: see LICENSE at the repository root.
 * =============================================================================
 */

#include "CAN_Driver/CAN_Driver.h"
#include "Motor_Control/Motor_Control.h"

// -----------------------------------------------------------------------------
//  User configuration
// -----------------------------------------------------------------------------
#define CAN_CS_PIN        53
#define CAN_INT_PIN       2        // set to -1 if INT is not wired
#define CONSOLE_BAUD      115200
#define TELEMETRY_BAUD    115200
#define CONTROL_HZ        200      // lower to 100 if the overrun counter grows

// Joint table. IDs 1-6 must match MOTOR_META in GUI_plotting_V4.py.
// Soft limits follow LIMITS in MATLAB/trajectory_generator.m (deg):
//   hip [-20, 40], knee [0, 50], ankle [-20, 20]
// `direction` must be checked on the real hardware: with the exo unloaded,
// command a small flexion and verify the joint flexes. Left and right motors
// are usually mirrored, hence the -1 on one side.
static const JointConfig JOINTS[6] = {
  // name           id  joint        side        dir  offset  min          max          kp     kd
  {"Right hip",     1,  JOINT_HIP,   SIDE_RIGHT, +1,  0.0f,   radians(-20), radians(40), 60.0f, 1.0f},
  {"Right knee",    2,  JOINT_KNEE,  SIDE_RIGHT, +1,  0.0f,   radians(0),   radians(50), 60.0f, 1.0f},
  {"Right ankle",   3,  JOINT_ANKLE, SIDE_RIGHT, +1,  0.0f,   radians(-20), radians(20), 60.0f, 1.0f},
  {"Left hip",      4,  JOINT_HIP,   SIDE_LEFT,  -1,  0.0f,   radians(-20), radians(40), 60.0f, 1.0f},
  {"Left knee",     5,  JOINT_KNEE,  SIDE_LEFT,  -1,  0.0f,   radians(0),   radians(50), 60.0f, 1.0f},
  {"Left ankle",    6,  JOINT_ANKLE, SIDE_LEFT,  -1,  0.0f,   radians(-20), radians(20), 60.0f, 1.0f},
};

// -----------------------------------------------------------------------------
//  Objects
// -----------------------------------------------------------------------------
AKCanBus canBus(CAN_CS_PIN, CAN_INT_PIN);
ExoController<6> exo(canBus, JOINTS);

const unsigned long PERIOD_US = 1000000UL / CONTROL_HZ;
unsigned long next_tick_us = 0;
unsigned long overruns = 0;
unsigned long max_exec_us = 0;
uint8_t telemetry_idx = 0;

void handleConsole();

// -----------------------------------------------------------------------------
void setup() {
  Serial.begin(CONSOLE_BAUD);
  Serial1.begin(TELEMETRY_BAUD);

  // Replace AK70_10_LIMITS by AK_LEGACY_SKETCH_LIMITS only if CubeMarsTool
  // shows those ranges for your firmware (see CAN_Protocol/motor_commands.md).
  canBus.setLimits(AK70_10_LIMITS);

  while (!canBus.begin(CAN_1000KBPS, MCP_8MHZ)) {
    Serial.println(F("[ERR] MCP2515 init failed - check wiring / crystal. Retrying..."));
    delay(1000);
  }
  Serial.println(F("[OK] CAN @ 1 Mbps"));
  Serial.println(F("OpenRehEx ready. Commands: e s p d c z + - f l ?"));
  next_tick_us = micros() + PERIOD_US;
}

// -----------------------------------------------------------------------------
void loop() {
  handleConsole();

  const unsigned long now = micros();
  if ((long)(now - next_tick_us) < 0) return;          // not yet time
  next_tick_us += PERIOD_US;
  if ((long)(now - next_tick_us) > 0) {                // fell behind
    overruns++;
    next_tick_us = now + PERIOD_US;
  }

  const unsigned long t0 = micros();
  exo.update(1.0f / CONTROL_HZ);

  // One telemetry line per cycle, round-robin over the six motors
  // (6 x ~25 bytes spread over 6 cycles keeps Serial1 well below 115200 baud)
  if (exo.state() != EXO_DISABLED) {
    exo.sendTelemetry(Serial1, telemetry_idx);
    telemetry_idx = (telemetry_idx + 1) % 6;
  }

  const unsigned long exec = micros() - t0;
  if (exec > max_exec_us) max_exec_us = exec;
}

// -----------------------------------------------------------------------------
void handleConsole() {
  while (Serial.available()) {
    const char c = (char)Serial.read();
    switch (c) {
      case 'e':
        Serial.println(exo.enable() ? F("[OK] enabled, holding posture")
                                    : F("[ERR] enable failed, see status"));
        break;
      case 's': exo.startWalking(); Serial.println(F("start (ramp in)")); break;
      case 'p': exo.stopWalking();  Serial.println(F("pause (ramp out)")); break;
      case 'd': exo.disable();      Serial.println(F("disabled - motors free")); break;
      case 'c': exo.clearFault();   Serial.println(F("fault cleared")); break;
      case 'z':
        Serial.println(exo.zeroHere() ? F("zero set") : F("zero only in DISABLED/HOLD"));
        break;
      case '+': exo.setAmplitude(exo.amplitude() + 0.05f); break;
      case '-': exo.setAmplitude(exo.amplitude() - 0.05f); break;
      case 'f': exo.setStrideTime(exo.strideTime() - 0.25f); break;
      case 'l': exo.setStrideTime(exo.strideTime() + 0.25f); break;
      case '?':
        exo.printStatus(Serial);
        Serial.print(F("  loop: ")); Serial.print(CONTROL_HZ);
        Serial.print(F(" Hz, max exec us=")); Serial.print(max_exec_us);
        Serial.print(F(", overruns=")); Serial.println(overruns);
        break;
      default: break;   // ignore CR/LF and unknown characters
    }
    if (c == '+' || c == '-' || c == 'f' || c == 'l') {
      Serial.print(F("amp=")); Serial.print(exo.amplitude(), 2);
      Serial.print(F("  stride_s=")); Serial.println(exo.strideTime(), 2);
    }
  }
}

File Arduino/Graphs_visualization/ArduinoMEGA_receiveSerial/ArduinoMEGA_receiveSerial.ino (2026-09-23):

/*
 * =============================================================================
 *  OpenRehEx - ArduinoMEGA_receiveSerial.ino
 *  Firmware for the VISUALIZATION Arduino MEGA 2560
 * =============================================================================
 *
 *  Receives telemetry lines from the CONTROL MEGA on Serial1 (RX1 = D19) and
 *  forwards the valid ones to the PC over USB (Serial) for GUI_plotting_V4.py.
 *
 *  Line format (5 integers, comma separated, '\n' terminated):
 *      motor_id,timestamp_ms,ref_mrad,pos_mrad,torque_mNm
 *
 *  Wiring: CONTROL TX1 (D18) -> VISUALIZATION RX1 (D19), and a common GND.
 *
 *  Changes vs. the first version: fixed-size char buffer instead of String
 *  (no heap fragmentation), all five fields validated, overlong lines dropped.
 * =============================================================================
 */

const uint8_t LINE_MAX = 48;
char line[LINE_MAX];
uint8_t len = 0;
bool overflow = false;

void setup() {
  Serial.begin(115200);    // USB -> PC (Python GUI)
  Serial1.begin(115200);   // UART <- control MEGA
}

void loop() {
  while (Serial1.available()) {
    const char c = (char)Serial1.read();
    if (c == '\r') continue;
    if (c == '\n') {
      line[len] = '\0';
      if (!overflow && isValidPacket(line)) Serial.println(line);
      len = 0;
      overflow = false;
    } else if (len < LINE_MAX - 1) {
      line[len++] = c;
    } else {
      overflow = true;     // discard the rest of this line
    }
  }
}

// Exactly five fields, each an optionally signed integer.
bool isValidPacket(const char* s) {
  uint8_t fields = 0;
  bool digits = false;
  for (const char* p = s; ; p++) {
    const char c = *p;
    if (c == ',' || c == '\0') {
      if (!digits) return false;
      fields++;
      digits = false;
      if (c == '\0') break;
    } else if (c == '-' && (p == s || *(p - 1) == ',')) {
      // sign allowed only at the start of a field
    } else if (c >= '0' && c <= '9') {
      digits = true;
    } else {
      return false;
    }
  }
  return fields == 5;
}

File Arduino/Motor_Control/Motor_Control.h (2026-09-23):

/*
 * =============================================================================
 *  OpenRehEx - Motor_Control.h
 *  Joint-level control of the six AK70-10 actuators (hip, knee, ankle x 2)
 * =============================================================================
 *
 *  Responsibilities
 *    - Joint configuration (CAN ID, sign, soft limits, impedance gains)
 *    - State machine: DISABLED -> HOLD -> RAMP_IN -> WALKING -> RAMP_OUT -> HOLD
 *                     any state -> FAULT (damping only) on a safety violation
 *    - Gait reference generation from the PROGMEM table (gait_trajectory.h)
 *      with amplitude scaling, adjustable stride time and a 50 % phase offset
 *      between the right and the left leg
 *    - One MIT impedance command per joint per control cycle:
 *          tau = kp (p_ref - p) + kd (v_ref - v) + t_ff
 *    - Safety supervision: CAN reply time-out, joint range, motor error codes
 *    - Telemetry lines for the visualization MEGA / Python GUI
 *
 *  Header-only for the same reason as CAN_Driver.h (Arduino IDE build rules).
 *
 *  Coordinates
 *    "joint" = anatomical angle used by MATLAB (hip/knee +flexion,
 *              ankle +dorsiflexion), in rad.
 *    "motor" = AK70-10 output-shaft angle reported over CAN, in rad.
 *    motor = direction * joint + offset
 *
 *  License: see LICENSE at the repository root.
 * =============================================================================
 */

#ifndef OPENREHEX_MOTOR_CONTROL_H
#define OPENREHEX_MOTOR_CONTROL_H

#include <Arduino.h>
#include <avr/pgmspace.h>
#include "../CAN_Driver/CAN_Driver.h"
#include "gait_trajectory.h"

// -----------------------------------------------------------------------------
//  Types
// -----------------------------------------------------------------------------
enum JointType : uint8_t { JOINT_HIP = 0, JOINT_KNEE = 1, JOINT_ANKLE = 2 };
enum LegSide   : uint8_t { SIDE_RIGHT = 0, SIDE_LEFT = 1 };

struct JointConfig {
  const char* name;
  uint8_t   can_id;       // AK70-10 CAN ID (set with CubeMarsTool)
  JointType joint;
  LegSide   side;
  int8_t    direction;    // +1 or -1: motor sign relative to the joint sign
  float     offset_rad;   // motor angle at anatomical zero (0 if zeroed there)
  float     min_rad;      // soft limit, joint coordinates
  float     max_rad;
  float     kp;           // N*m/rad
  float     kd;           // N*m*s/rad
};

enum ExoState : uint8_t {
  EXO_DISABLED = 0,   // motors out of MIT mode (free)
  EXO_HOLD,           // hold current posture
  EXO_RAMP_IN,        // smooth transition from posture to gait start
  EXO_WALKING,        // tracking the gait trajectory
  EXO_RAMP_OUT,       // smooth transition back to neutral standing
  EXO_FAULT           // damping only, waits for operator
};

enum FaultCode : uint8_t {
  FAULT_NONE = 0,
  FAULT_NO_REPLY,       // motor did not answer within COMM_TIMEOUT_MS
  FAULT_RANGE,          // measured angle outside soft limits + margin
  FAULT_MOTOR_ERROR,    // motor reported an error code
  FAULT_ENABLE_FAILED   // motor did not answer while entering MIT mode
};

struct ControlSettings {
  float    ramp_time_s;          // duration of RAMP_IN / RAMP_OUT
  float    stride_time_s;        // initial stride (gait cycle) duration
  float    amplitude;            // initial amplitude scale (0..1)
  float    amplitude_rate;       // max amplitude change per second
  float    range_margin_rad;     // tolerance beyond soft limits before FAULT
  float    fault_kd;             // damping applied in FAULT
  float    max_ff_velocity;      // clamp for velocity feed-forward [rad/s]
  uint16_t reply_timeout_us;     // wait for each MIT reply
  uint16_t comm_timeout_ms;      // no valid reply for this long -> FAULT
  bool     zero_on_enable;       // send "set zero" when enabling (see README)
  bool     fault_on_motor_error; // use byte 7 of the reply (firmware >= V2)
};

static const ControlSettings DEFAULT_SETTINGS = {
  3.0f,    // ramp_time_s
  3.0f,    // stride_time_s   (slow rehabilitation gait to start with)
  0.5f,    // amplitude       (50 % of the MATLAB trajectory to start with)
  0.10f,   // amplitude_rate
  0.15f,   // range_margin_rad (~8.6 deg)
  2.0f,    // fault_kd
  6.0f,    // max_ff_velocity
  1500,    // reply_timeout_us
  50,      // comm_timeout_ms
  true,    // zero_on_enable  (same behaviour as the original sketch)
  true     // fault_on_motor_error
};

// -----------------------------------------------------------------------------
//  Gait table access
// -----------------------------------------------------------------------------
namespace gait {

inline float tableRad(const int16_t* table, uint16_t i) {
  return (float)(int16_t)pgm_read_word(&table[i]) * 0.001f;
}

// phase in [0,1): linear interpolation over the periodic table
inline float sample(JointType j, float phase) {
  const int16_t* table = (j == JOINT_HIP)  ? GAIT_HIP_MRAD
                       : (j == JOINT_KNEE) ? GAIT_KNEE_MRAD
                                           : GAIT_ANKLE_MRAD;
  phase -= floor(phase);
  const float x = phase * GAIT_N;
  uint16_t i0 = (uint16_t)x;
  if (i0 >= GAIT_N) i0 = GAIT_N - 1;
  const uint16_t i1 = (i0 + 1 == GAIT_N) ? 0 : i0 + 1;
  const float a = x - (float)i0;
  return tableRad(table, i0) * (1.0f - a) + tableRad(table, i1) * a;
}

}  // namespace gait
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

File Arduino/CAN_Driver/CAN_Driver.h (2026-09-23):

/*
 * =============================================================================
 *  OpenRehEx - CAN_Driver.h
 *  CubeMars AK-series (AK70-10) MIT-mode driver over an MCP2515 CAN module
 * =============================================================================
 *
 *  Header-only on purpose: the Arduino IDE only compiles .cpp files located in
 *  the sketch root or in src/, so keeping the implementation inline lets
 *  main.ino include this file from a sub-folder without extra build steps.
 *
 *  Dependencies
 *    - MCP_CAN library by coryjfowler  (Library Manager: "mcp_can")
 *    - SPI (built in)
 *
 *  Frame layouts are documented in CAN_Protocol/motor_commands.md.
 *
 *  License: see LICENSE at the repository root.
 * =============================================================================
 */

#ifndef OPENREHEX_CAN_DRIVER_H
#define OPENREHEX_CAN_DRIVER_H

#include <Arduino.h>
#include <SPI.h>
#include <mcp_can.h>

// -----------------------------------------------------------------------------
//  MIT-mode scaling limits
// -----------------------------------------------------------------------------
//  These ranges define how floats are mapped to the 16/12-bit integers inside
//  every MIT frame. They MUST match the motor firmware, otherwise commanded and
//  measured velocity/torque are scaled incorrectly (position is usually still
//  right because P_MIN/P_MAX = +/-12.5 is common to all AK firmwares).
//
//  Check the values for your firmware in CubeMarsTool (CAN_Protocol/) or in the
//  AK70-10 product manual, section "MIT power mode communication protocol".
struct MitLimits {
  float p_min,  p_max;   // rad
  float v_min,  v_max;   // rad/s
  float kp_min, kp_max;  // N*m/rad
  float kd_min, kd_max;  // N*m*s/rad
  float t_min,  t_max;   // N*m
};

// AK70-10 values listed by CubeMars for MIT mode.
static const MitLimits AK70_10_LIMITS = {
  -12.5f, 12.5f,
  -50.0f, 50.0f,
    0.0f, 500.0f,
    0.0f,   5.0f,
  -25.0f, 25.0f
};

// Values used in the original CubemarsAK_one_motor.ino sketch (kept for
// reference / backwards comparison with previously recorded data).
static const MitLimits AK_LEGACY_SKETCH_LIMITS = {
  -12.5f, 12.5f,
  -30.0f, 30.0f,
    0.0f, 500.0f,
    0.0f,   5.0f,
  -18.0f, 18.0f
};

// -----------------------------------------------------------------------------
//  Data containers
// -----------------------------------------------------------------------------
struct MitCommand {
  float p;    // desired position        [rad]
  float v;    // desired velocity        [rad/s]
  float kp;   // position gain           [N*m/rad]
  float kd;   // velocity gain           [N*m*s/rad]
  float t;    // feed-forward torque     [N*m]
};

struct MitFeedback {
  uint8_t  id;          // motor CAN ID reported in byte 0
  float    p;           // measured position   [rad]
  float    v;           // measured velocity   [rad/s]
  float    t;           // measured torque     [N*m]
  uint8_t  temp_raw;    // byte 6: driver temperature (firmware >= V2 only;
                        //   scaling/offset depends on firmware, see manual)
  uint8_t  error;       // byte 7: error code  (firmware >= V2 only)
  bool     has_status;  // true if the frame carried temp/error bytes
};

// Error codes reported in byte 7 of the reply (firmware >= V2)
enum AkErrorCode : uint8_t {
  AK_OK              = 0,
  AK_OVER_TEMP       = 1,
  AK_OVER_CURRENT    = 2,
  AK_OVER_VOLTAGE    = 3,
  AK_UNDER_VOLTAGE   = 4,
  AK_ENCODER_FAULT   = 5,
  AK_PHASE_UNBALANCE = 6
};

// -----------------------------------------------------------------------------
//  Fixed-point helpers (shared with the Python tools, see motor_commands.md)
// -----------------------------------------------------------------------------
namespace akcan {

inline uint16_t floatToUint(float x, float x_min, float x_max, uint8_t bits) {
  const float span = x_max - x_min;
  const float max_int = (float)((1UL << bits) - 1UL);
  if (x < x_min) x = x_min;
  if (x > x_max) x = x_max;
  return (uint16_t)((x - x_min) * max_int / span + 0.5f);   // rounded
}

inline float uintToFloat(uint16_t x_int, float x_min, float x_max, uint8_t bits) {
  const float span = x_max - x_min;
  const float max_int = (float)((1UL << bits) - 1UL);
  return ((float)x_int) * span / max_int + x_min;
}

// Pack a MIT command into 8 bytes
inline void packCommand(const MitCommand& c, const MitLimits& L, uint8_t buf[8]) {
  const uint16_t p  = floatToUint(c.p,  L.p_min,  L.p_max,  16);
  const uint16_t v  = floatToUint(c.v,  L.v_min,  L.v_max,  12);
  const uint16_t kp = floatToUint(c.kp, L.kp_min, L.kp_max, 12);
  const uint16_t kd = floatToUint(c.kd, L.kd_min, L.kd_max, 12);
  const uint16_t t  = floatToUint(c.t,  L.t_min,  L.t_max,  12);

  buf[0] = (uint8_t)(p >> 8);
  buf[1] = (uint8_t)(p & 0xFF);
  buf[2] = (uint8_t)(v >> 4);
  buf[3] = (uint8_t)(((v & 0x0F) << 4) | (kp >> 8));
  buf[4] = (uint8_t)(kp & 0xFF);
  buf[5] = (uint8_t)(kd >> 4);
  buf[6] = (uint8_t)(((kd & 0x0F) << 4) | (t >> 8));
  buf[7] = (uint8_t)(t & 0xFF);
}

// Unpack a MIT reply (6 or 8 bytes)
inline bool unpackReply(const uint8_t* buf, uint8_t len, const MitLimits& L, MitFeedback& fb) {
  if (len < 6) return false;
  const uint16_t p = ((uint16_t)buf[1] << 8) | buf[2];
  const uint16_t v = ((uint16_t)buf[3] << 4) | (buf[4] >> 4);
  const uint16_t i = ((uint16_t)(buf[4] & 0x0F) << 8) | buf[5];

  fb.id = buf[0];
  fb.p  = uintToFloat(p, L.p_min, L.p_max, 16);
  fb.v  = uintToFloat(v, L.v_min, L.v_max, 12);
  fb.t  = uintToFloat(i, L.t_min, L.t_max, 12);

  fb.has_status = (len >= 8);
  fb.temp_raw = fb.has_status ? buf[6] : 0;
  fb.error  = fb.has_status ? buf[7] : 0;
  return true;
}

}  // namespace akcan
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
